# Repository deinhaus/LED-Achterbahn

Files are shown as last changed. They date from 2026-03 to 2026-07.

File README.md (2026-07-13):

GitHub Logo

Maker Media GmbH

***

# LED-Achterbahn

**Aus einem LED-Streifen, etwas Physik und einem ESP32 entsteht eine LED-Achterbahn, bei der das Licht wie ein echter Wagen durch Loopings und Kurven rauscht. Und das zugehörige Baukastensystem macht individuelle Streckendesigns zum Kinderspiel – ganz ohne Kleben, Schrauben oder manuelle Code-Anpassungen.**

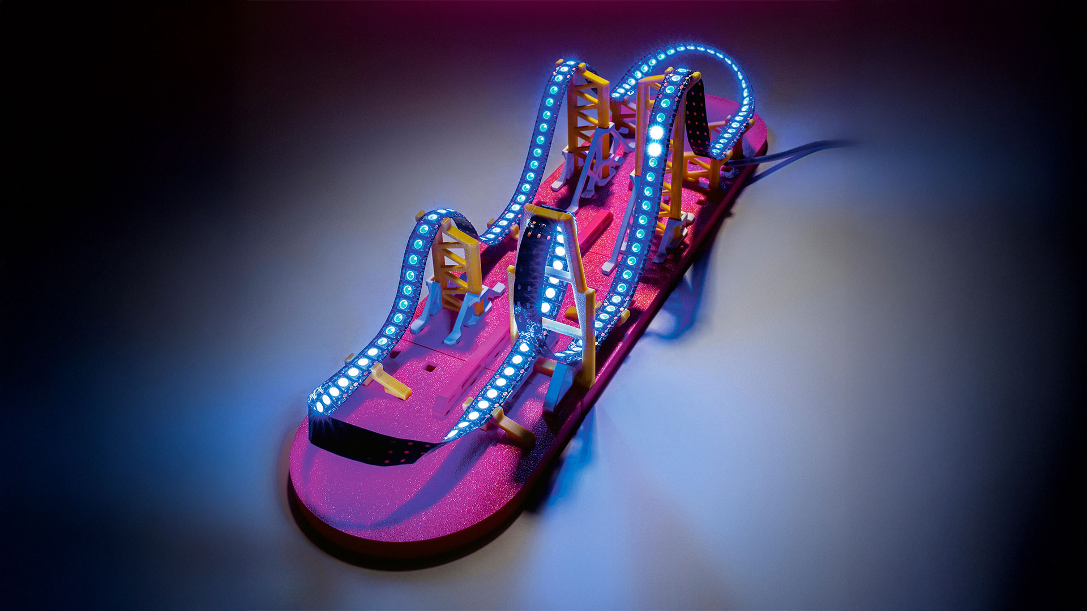
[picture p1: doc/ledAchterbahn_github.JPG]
Aufmacherbild aus dem Heft


Hier findet ihr die Daten für den 3D-Druck und den Arduino-Code.

Der vollständige Artikel zum Projekt steht in der **[Make-Ausgabe 2/26](https://www.heise.de/select/make/2026/2)**.

---
# Infos aus dem FORK<>

## umgesetzte Features
- ✅ Anbindung eines DFPlayer Mini für Audio-Effekte (Theme-Song, Zonen-Sounds, Zufallswiedergabe – siehe [Sound-System](#sound-system-dfplayer-mini))

## Hinweise zu G-Kräften in Telemetrie
Die G-Kräfte glätten (Der Code-Fix)
Da die Kurve in kleine lineare Stücke (Segmente) zerhackt wird, entstehen an den "Knickpunkten" zwischen den Segmenten oft winzige, aber extreme mathematische Spitzen in der Krümmung. Zudem ist ein echter Achterbahnzug lang und verteilt solche Spitzen.

Ich habe einen Tiefpassfilter (Moving Average) in den Code eingebaut, der die G-Kräfte weichzeichnet, wie es die Dämpfung eines echten Zuges tun würde. Zusätzlich habe ich die Auflösung der Kurven erhöht (const int intSteps = 40;) um eine feinere Abstufung zu erreichen.

Im Konfig-Menü ist jetzt ein Faktor konfigurierbar, der den angezeigten Wert n% abschwächt.

# Rollercoaster LED‑Simulation
*Interaktive Achterbahn‑Physik auf einem ESP32 mit OLED‑Display, Sound und bis zu 1000 LEDs.*








---

# 📖 Inhalt
1. [Überblick](#überblick)
2. [FPS‑Hinweise & Performance](#fps-hinweise--performance-tabelle)
3. [Features](#features)
4. [Hardware](#hardware)
5. [Verdrahtung](#verdrahtung)
6. [Stromversorgung](#stromversorgung)
7. [Installation](#installation)
8. [Sound-System (DFPlayer Mini)](#sound-system-dfplayer-mini)
9. [Bedienung & Menüsteuerung](#bedienung--menüsteuerung)
10. [Streckeneditor](#streckeneditor)
11. [Telemetrie & Kirmes-Modus](#telemetrie--kirmes-modus)
12. [Physik‑System](#physik-system)
13. [Dateisystem & Slots](#dateisystem--slots)
14. [Code‑Architektur](#code-architektur)
15. [Detaillierte Code‑Erklärung](#-detaillierte-code-erklärung)
16. [Troubleshooting Sound](#troubleshooting-sound)
17. [Lizenz](#lizenz)

---

# Überblick
- **rollercoaster_finale** ist **unverändert**.
- **Meine Änderungen** sind vollständig in **rollercoaster_extra** eingeflossen. Dieses Fork erweitert die Achterbahn um detailliertere Einstellungen, eine saubere Telemetrie mit Ziel-Logik, einen Kirmes-Modus mit dynamischen Sprüchen, eine optimierte Menüführung und ein vollständiges **Sound-System** auf Basis des DFPlayer Mini.

---

# FPS‑Hinweise & Performance‑Tabelle
Da der ESP32 gleichzeitig die Physik für bis zu 1000 LEDs berechnet und ein OLED-Display via I2C ansteuert, ist das richtige Timing entscheidend. Die folgende Tabelle zeigt, wie sich die Anzahl der LEDs auf die Datenraten, die maximal sinnvollen OLED‑FPS und das subjektive Fahrgefühl auswirken.

| **Anzahl LEDs** | **Zeit LED‑Daten** | **Zeit OLED‑Daten** | **Max. empfohlene OLED‑FPS** | **Effekt auf die LED‑Bahn** |
|---:|---:|---:|---:|---|
| 100  | 3 ms  | ~25 ms | 20–30 | Absolut flüssig, Ruckler nicht wahrnehmbar |
| 200  | 6 ms  | ~25 ms | 15–20 | Absolut flüssig |
| 300  | 9 ms  | ~25 ms | 15–20 | Sehr flüssig |
| 400  | 12 ms | ~25 ms | 12–15 | Sehr flüssig |
| 500  | 15 ms | ~25 ms | 10–15 | Flüssig |
| 600  | 18 ms | ~25 ms | 10–12 | Minimales Mikroruckeln messbar, kaum sichtbar |
| 700  | 21 ms | ~25 ms | 8–10  | Sehr stabiles Fahrgefühl |
| 800  | 24 ms | ~25 ms | 8–10  | Stabiles Fahrgefühl |
| 900  | 27 ms | ~25 ms | 6–8 | Leichte Ruckler beim Display‑Update möglich |
| 1000 | 30 ms | ~25 ms | 5–8 | Guter Kompromiss aus flüssiger Bahn und Telemetrie |

*Tipp: Die Display-FPS lassen sich im "Konfig"-Menü jederzeit anpassen. Standardwert ist 4 FPS.*

*Hinweis Sound: Die DFPlayer-Ansteuerung läuft über UART2 und wird bewusst ohne ACK-Wartezeiten betrieben (`isACK=false`), damit die Physik-Schleife nicht blockiert. Sound-Befehle haben dadurch keinen messbaren Einfluss auf die LED-Performance.*

---

# Features
- LED‑Achterbahn mit realistisch berechneter Physik
- Bis zu **1000 LEDs**
- **Sound-System mit 4 Modi:** Theme-Song mit Effekt-Einwürfen (Advertise), Zufallswiedergabe, nur Theme oder nur Effekte
- OLED‑Display mit Telemetrie (Aktiv/Ziel-Logik & Top-Speed Tracking)
- Vollständiger **Streckeneditor** direkt am Gerät mit Scroll-Menüs
- Lift, Brake, Booster, Loop, Helix, Steilkurve uvm.
- Zonen lassen sich temporär deaktivieren (Enabled/Disabled)
- Kirmes-Modus mit passenden Sprüchen zum jeweiligen Fahrabschnitt
- 5 Speicher‑Slots (LittleFS) inkl. Abwärtskompatibilität
- Farbcodierung nach Geschwindigkeit (Speed-Map)
- Bezier‑Interpolation für realistische Höhenprofile

---

# Hardware
- ESP32 DevKit (Empfohlen: ESP32-S3 für bessere FPU-Performance)
- SH1106 OLED 128×64 (I2C)
- WS2812B LED‑Strip
- Rotary Encoder mit Button (KY-040)
- **DFPlayer Mini** (⚠️ **Original YX5200 dringend empfohlen** – siehe [Troubleshooting](#troubleshooting-sound))
- microSD-Karte, max. 32 GB, FAT32
- Mono-Lautsprecher 4–8 Ω, max. 3 W
- 1 kΩ Widerstand (für die RX-Leitung des DFPlayer)
- Elko 470–1000 µF (Pufferung der DFPlayer-Versorgung)
- 5V Netzteil (je nach LED‑Anzahl 5–20A)

---

# Verdrahtung

## Pinbelegung ESP32

| ESP32-Pin | verbunden mit |
|---|---|
| GPIO 33 | LED-Streifen Datenleitung (DIN) |
| GPIO 25 | Encoder CLK |
| GPIO 26 | Encoder DT |
| GPIO 27 | Encoder Taster (SW) |
| GPIO 21 | OLED SDA (I2C) |
| GPIO 22 | OLED SCL (I2C) |
| GPIO 17 | DFPlayer RX (**über 1 kΩ Widerstand!**) |
| GPIO 16 | DFPlayer TX (direkt) |

## Anschluss DFPlayer Mini

Modul so halten, dass der SD-Karten-Slot nach oben zeigt. Pin 1 (VCC) ist dann oben links; die linke Seite zählt von oben nach unten durch.

| DFPlayer-Pin  | verbunden mit |
|---|---|
| VCC (Pin 1) | 5 V |
| RX  (Pin 2) | ESP32 GPIO 17, **1 kΩ Widerstand in Serie** |
| TX  (Pin 3) | ESP32 GPIO 16 (direkt) |
| SPK_1 (Pin 6) | Lautsprecher + |
| GND (Pin 7) | Masse (gemeinsam mit ESP32 und Netzteil!) |
| SPK_2 (Pin 8) | Lautsprecher − |

Alle übrigen Pins (BUSY, DAC, ADKEY, IO, USB) bleiben frei. Die freien Pins der rechten Modulseite dürfen nichts berühren – ADKEY/IO lösen sonst ungewollt Wiedergabe aus.

Der 1-kΩ-Widerstand dämpft den Pegelunterschied zwischen dem 3,3-V-Signal des ESP32 und dem 5-V-Eingang des Players. Ohne ihn funktioniert die Kommunikation zwar, es entsteht aber häufig ein leises Dauerrauschen im Lautsprecher.

---

# Stromversorgung

⚠️ **Der häufigste Fehler beim Nachbau:** LED-Streifen und Sound gemeinsam am USB-Port betreiben. Die Folge sind Brummen aus dem Lautsprecher, abgehackte Sounds, Ruckler und komplette Systemabstürze, die nur ein Kaltstart behebt.

Regeln für einen stabilen Betrieb:
- **LED-Streifen zwingend an ein ausreichend dimensioniertes 5-V-Netzteil**, niemals inkl. Sound über USB versorgen.
- Bei 1000 LEDs den Strom an **mehreren Punkten** einspeisen (Anfang, Mitte, Ende).
- **Elko 470–1000 µF direkt an VCC/GND des DFPlayer** (Polung beachten: Minus-Streifen an GND). Puffert die Stromspitzen des 3-W-Verstärkers.
- **Alle Massen verbinden** (Netzteil, ESP32, DFPlayer, LED-Streifen), sternförmig zum Netzteil geführt – nicht als lange Kette.
- Der ESP32 selbst kann am USB bleiben (praktisch zum Flashen), der DFPlayer sollte mit eigener Zuleitung ans Netzteil.
- Nach Tests das System **10–15 Sekunden stromlos** lassen: Der Elko hält den DFPlayer sonst am Leben und alte Zustände (Loop-Modus, Lautstärke) überleben den vermeintlichen Neustart.

---

# Installation
1. Repository klonen
2. Arduino IDE öffnen (ESP32 Boardverwalter muss installiert sein)
3. Bibliotheken installieren:
   - Adafruit GFX Library
   - Adafruit SH110X
   - Adafruit NeoPixel
   - RotaryEncoder (von Matthias Hertel)
   - LittleFS (ESP32)
   - **DFRobotDFPlayerMini** (von DFRobot)
4. Taktfrequenz in der IDE auf 240 MHz stellen (für maximale Physik-Performance).
5. SD-Karte für den DFPlayer vorbereiten (siehe [Sound-System](#sound-system-dfplayer-mini)).
6. Sketch hochladen.

---

# Sound-System (DFPlayer Mini)

## SD-Karten-Struktur

- Max. 32 GB, **FAT32** formatiert (nicht exFAT – Karten über 32 GB formatiert Windows standardmäßig als exFAT!)
- Dateien **einzeln in numerischer Reihenfolge** kopieren (der Player adressiert intern nach FAT-Reihenfolge)
- Bei macOS versteckte `._`-Dateien entfernen: `dot_clean /Volumes/SD`

```
SD-Karte (Root)
├── mp3/
│   ├── 0001.mp3   Kettenlift          (Modus "Effekte")
│   ├── 0002.mp3   Booster / Launch    (Modus "Effekte")
│   ├── 0003.mp3   Bremse / Zischen    (Modus "Effekte")
│   ├── 0004.mp3   Theme-Song          (Modus "Theme+FX" und "Theme")
│   └── 0005.mp3   Welcome / Start     (Modus "Effekte", beim Fahrtbeginn)
├── ADVERT/
│   ├── 0001.mp3   Kettenlift   ┐
│   ├── 0002.mp3   Booster      ├─ identische Dateien wie /mp3/0001–0003,
│   └── 0003.mp3   Bremse       ┘  als Einwurf für Modus "Theme+FX"
└── 02/
    ├── 001.mp3    ┐
    ├── 002.mp3    ├─ beliebig viele Random-Tracks (Modus "Random"),
    └── ...        ┘  lückenlos nummeriert
```

**Namenskonventionen:**
- `/mp3` und `/ADVERT`: Dateinamen mit **vier** Ziffern (`0001.mp3`)
- Nummerierte Ordner (`02`): Ordnername **zwei** Ziffern, Dateien **drei** Ziffern (`001.mp3`)
- Der Ordnername `ADVERT` muss exakt so lauten (Großbuchstaben)

## Die vier Sound-Modi

| Modus | Verhalten |
|---|---|
| **Theme+FX** | Theme-Song läuft in Schleife. Fährt der Wagen in eine Zone, wird der passende Effekt per **Advertise** eingeblendet – danach läuft der Theme automatisch an der unterbrochenen Stelle weiter. Verlässt der Wagen den Lift, wird dessen Sound sofort beendet (`stopAdvertise`). |
| **Random** | Zufällige Tracks aus `/02` in Endlosschleife. Läuft komplett ununterbrochen – Zonen haben keinen Einfluss. |
| **Theme** | Nur der Theme-Song in Schleife, keine Effekte. |
| **Effekte**  | Stille bei freier Fahrt; Zonen-Sounds als Einzeltracks (Lift loopt, Booster/Bremse laufen einmal aus). Beim Fahrtstart wird der Welcome-Sound gespielt, geschützt durch eine Schonfrist. |

## Technische Details
- Kommunikation über **UART2** (Hardware-Serial, 9600 Baud)
- Initialisierung mit `begin(dfpSerial, /*isACK=*/false, /*doReset=*/true)`: Der abgeschaltete ACK-Check verhindert, dass Befehle wie `stop()` die Hauptschleife blockieren; der Reset sorgt für einen definierten Startzustand. Bis zu 3 Initialisierungsversuche.
- Die Anzahl der Random-Tracks wird beim Boot per `readFileCountsInFolder()` ermittelt (doppelte Abfrage, da der erste Wert nach dem Reset unzuverlässig sein kann).
- Die Sound-Logik reagiert auf **Kategorie-Wechsel** (LIFT/BOOST/BRAKE/RIDE), nicht auf jeden Statuswechsel – "FREIE FAHRT" und "AUSROLLEN" teilen sich einen Sound, damit Tracks nicht grundlos abbrechen.
- Track-Wiederholung (Theme, Lift-Loop) läuft über den `DFPlayerPlayFinished`-Event statt über den unzuverlässigen internen Loop-Modus. Eine 300-ms-Sperre fängt doppelte Finish-Events ab.

---

# Bedienung & Menüsteuerung
Die komplette Steuerung erfolgt intuitiv über den **Drehencoder**:
- **Drehen:** Navigiert durch Listen oder ändert Werte.
- **Drücken:** Bestätigt eine Auswahl oder wechselt in die nächste Menüebene.

### Das Hauptmenü
- **ABSPIELEN:** Startet die Echtzeit-Simulation der aktuell geladenen Strecke.
- **KONFIG:** Hier lassen sich visuelle und akustische Parameter anpassen:
  - Wagen- und Bahnfarbe (inkl. Speed-Map)
  - Helligkeit für Wagen, Bahn und Zonen (Lift, Brake, Booster)
  - Wagenlänge (Anzahl der LEDs)
  - Zonen-Effekte (Aus, Statisch, Lauflicht/Pulsieren)
  - OLED FPS und Display-Modus (Telemetrie vs. Kirmes)
  - Hilfparameter (G-Factor, MaxSpeed für color-speed-map)
  - **Sound-V:** Lautstärke 0–30, mit Live-Hörprobe beim Drehen
  - **Sound:** Sound global An/Aus
  - **S-Modus:** Auswahl des Sound-Modus (Theme+FX / Random / Theme / Effekte)
- **STRECKE ANPASSEN:** Zugang zum Streckeneditor (Bearbeiten, Neu hinzufügen).
- **STRECKEN [Sx]:** Dateimanager. Zeigt den aktuell geladenen Slot (S1-S5) an.

*Hinweis: Längere Menüs (wie z.B. bei der Element-Bearbeitung oder Konfig) verfügen über einen **dynamischen Scroll-Viewport**, sodass immer 6-7 Zeilen sichtbar sind und der Cursor flüssig mitläuft.*

*Wichtig: Einstellungen werden erst beim Verlassen des KONFIG-Menüs über ZURUECK in den aktiven Slot gespeichert.*

---

# Streckeneditor
Der Editor ermöglicht es, die physikalischen Eigenschaften der Strecke direkt am LED-Band zu "zeichnen". Die Strecke besteht aus "Nodes" (Knotenpunkten).

1. **Startpunkt setzen:** Definiert die Position (LED) und die Starthöhe.
2. **Elemente hinzufügen:** Du navigierst die "grüne LED" an die gewünschte Position auf dem Streifen, stellst die Höhe ein und wählst die Art des Elements (Hill, Loop, Helix, etc.).
3. **Funktions-Zonen (Lift, Brake, Booster):** Diese speziellen Elemente benötigen weitere Parameter:
   - **Wert (Force):** m/s für Lift/Bremse oder Schubkraft für den Booster.
   - **Länge:** Wie viele LEDs lang diese Zone aktiv sein soll.
   - **Aktiv/Inaktiv:** Zonen können zu Testzwecken schnell an- oder ausgeschaltet werden, ohne sie löschen zu müssen.
4. **Endpunkt:** Schließt die Strecke ab. Das System berechnet automatisch die Bezier-Kurven und die Beschleunigungswerte für jedes Teilstück dazwischen.

---

# Telemetrie & Kirmes-Modus
Während der Fahrt liefert das OLED-Display Live-Daten. Es gibt zwei Darstellungsmodi, die im Konfig-Menü umgestellt werden können.

### Modus 0: Telemetrie (Der Nerd-Modus)
Liefert exakte Daten zur Physik-Engine:
- **Pos:** Aktuelle LED-Position des Wagens / Gesamtlänge.
- **Spd m/s:** Aktuelle Geschwindigkeit in Metern pro Sekunde, inkl. der **(max xx.x)** Anzeige für den bisherigen Top-Speed des Runs.
- **G:** Aktuelle G-Kräfte inkl. der **(max xx.x/min xx.x)** Anzeige für den bisherigen Top-Wert des Runs.
- **Status:** Zeigt an, ob der Wagen frei fährt (FREIE FAHRT), gebremst wird, auf dem Lift hängt oder geboostet wird.
- **Ziele & Zonen:**
  - `AKTIV: Elem X (Typ)`: Wird angezeigt, solange sich der Wagen *physisch innerhalb* der Länge einer Zone (z.B. eines Lifts) befindet.
  - `ZIEL: Elem Y (Typ)`: Fährt der Wagen frei, zeigt das System das nächste vorausliegende Element an.
- **LED & H:** Genaue Position und Höhe des aktuellen/nächsten Elements.

### Modus 1: Jahrmarkt Live (Der Show-Modus)
Perfekt, wenn die Bahn fertig aufgebaut ist. Zeigt nur den aktuellen Speed (inkl. Max) und präsentiert einen zufällig gewählten, dynamischen Spruch passend zur aktuellen Streckensituation (z.B. *"Zischhh... Bremsen greifen!"* oder *"Kopfueber ins Glueck! Looping in Sicht!"*). In Kombination mit dem Sound-Modus **Theme+FX** entsteht so echtes Kirmes-Feeling.

---

# Physik‑System
Das Kernstück der Simulation. Der Code unterteilt die Bezier-Interpolation der Strecke in winzige Segmente.
- **Beschleunigung:** Wird durch den Hangabtrieb ($a = g \cdot \sin(\alpha)$) in jedem Segment bestimmt.
- **Reibung & Luftwiderstand:** Wirken dynamisch gegen die Bewegungsrichtung, abhängig von der aktuellen Geschwindigkeit ($v^2$).
- **Funktionszonen:** Überschreiben die Physik. Ein Lift zwingt den Wagen auf eine konstante Geschwindigkeit, eine Bremse baut Energie ab, ein Booster addiert Beschleunigung.
- Die Berechnung erfolgt zeitbasiert (`dt = millis() - lastTime`), um die Geschwindigkeit unabhängig von der CPU-Auslastung stabil zu halten.

---

# Dateisystem & Slots
Die Strecken werden im Flash-Speicher des ESP32 via LittleFS abgelegt.
- Bis zu **5 Strecken** speicherbar (Slot 1 bis Slot 5).
- Speichert alle Nodes, Optik-Einstellungen, Helligkeiten, FPS **und die Sound-Einstellungen** (Lautstärke, An/Aus, Sound-Modus).
- **Migration / Abwärtskompatibilität:** Der Code nutzt einen `FILE_MAGIC` Header mit Versionsnummer (aktuell **V6**). Alte Strecken werden beim Laden automatisch migriert: fehlende Felder erhalten sinnvolle Standardwerte (z.B. Zonen auf aktiv, Lautstärke 20, Sound-Modus Theme+FX).
- Funktionen: Laden, Neu erstellen (löscht den RAM und beginnt bei LED 0), Neu berechnen (falls die Bezier-Kurven haken) und Löschen (entfernt die .bin Datei aus dem Flash).

---

# Code‑Architektur
- **State‑Machine (UI_STATE):** Über 40 Zustände steuern, was gerade auf dem Display gerendert wird und wie der Encoder reagiert (z.B. `ST_EDIT_NODE_FORCE`, `ST_OPTICS_SOUND_MODE` oder `ST_PLAY`).
- **Nodes (`Node`):** Die Stützpfeiler der Strecke. Enthalten Typ, Höhe und ggf. Spezialfunktionen.
- **Bezier‑Interpolation (`calculations`, `bezierCalculations`):** Generiert aus wenigen Nodes eine geschwungene, realistische Bahn.
- **Segment‑Physik (`segmentCalculations`):** Wandelt die Bezier-Punkte in physikalische Steigungen um.
- **Sound-Logik (`updateSound`, `playRandomSound`, `stopSound`):** Bildet den Fahrstatus auf Sound-Kategorien ab und steuert den DFPlayer je nach gewähltem Modus. Der `DFPlayerPlayFinished`-Event in `moveLED()` übernimmt Theme-Wiederholung, Lift-Loop und Random-Weiterschaltung.
- **Renderer:** Getrennte Ausgabe für LEDs (`moveLED`, `drawSetupLeds`, `drawColorSelection`) und das Display (vielfältige `draw...` Funktionen).

---

# 🧩 Detaillierte Code‑Erklärung

## Bibliotheken & Hardware‑Setup
Der Code nutzt:
- `Adafruit_SH1106G` → OLED‑Display (I2C)
- `Adafruit_NeoPixel` → LED‑Streifen (WS2812B)
- `RotaryEncoder` → Interrupt-basierte Encoder-Auswertung für präzises Drehen.
- `LittleFS` → Dateisystem
- `Wire` → I²C für Display
- `DFRobotDFPlayerMini` → Sound-Ausgabe über UART2 (GPIO 16/17)

## Datenstrukturen

### Node
```cpp
struct Node {
  uint16_t pos;      // Position auf dem LED-Streifen
  uint16_t height;   // "Bauhöhe" des Elements
  uint8_t  type;     // 0=Start, 1=Scheitel, 2=Ende
  uint8_t  art;      // Welches Streckenelement (Hill, Loop, Lift...)
  float    force;    // Kraft/Zielgeschwindigkeit
  uint16_t length;   // Ausdehnung des Elements in LEDs
  uint8_t  enabled;  // 1 = Aktiviert, 0 = Übersprungen
};
```

### Sound-Konstanten
```cpp
#define SND_LIFT      1    // /mp3/0001.mp3 (Modus "Effekte")
#define SND_BOOSTER   2    // /mp3/0002.mp3
#define SND_BRAKE     3    // /mp3/0003.mp3
#define SND_THEME     4    // /mp3/0004.mp3 (Modi "Theme+FX" und "Theme")
#define SND_START     5    // /mp3/0005.mp3 (Welcome im Modus "Effekte")
#define ADV_LIFT      1    // /ADVERT/0001.mp3 (Einwürfe im Modus "Theme+FX")
#define ADV_BOOSTER   2    // /ADVERT/0002.mp3
#define ADV_BRAKE     3    // /ADVERT/0003.mp3
#define RANDOM_FOLDER 2    // Ordner /02 (Modus "Random")
```

---

# Troubleshooting Sound

| Symptom | Ursache | Lösung |
|---|---|---|
| "DFPlayer nicht gefunden" | RX/TX vertauscht, fehlende gemeinsame Masse oder SD-Indizierung noch nicht fertig | Leitungen kreuzen (TX→RX), alle GND verbinden, `delay(1000)` vor `begin()` |
| Ordner wird als leer gemeldet, Abspielen geht aber | Clone-Chip (z.B. GD3200B, MH2024K) – `readFileCountsInFolder()` defekt | Original YX5200 verwenden oder Track-Anzahl fest im Code hinterlegen |
| Spontanes Abspielen beim Einschalten | Clone-Chip mit Auto-Play oder freischwebende ADKEY/IO-Pins | Original verwenden; rechte Pin-Reihe freihalten |
| Brummen, das lauter wird und mit Knacken endet | Verstärker schwingt in der Boot-Phase auf verrauschter Versorgung | LED-Streifen an eigenes Netzteil, Elko an den Player, 1-kΩ-Widerstand |
| Brummen/Kratzen im Betrieb, System friert ein | LED-Streifen und Player teilen sich die USB-Versorgung | **Separates Netzteil für die LEDs** – wichtigste Einzelmaßnahme!  Ich versorge alles mit einem 5V/5A Netzteil, über USB kann der Strom ggf nicht genügen, wenn zu viele LEDs gleichzeitig oder zu hell leuchten. |
| `stop()` oder andere Befehle hängen | Bibliothek wartet auf ACK-Antwort, Rückleitung (Player-TX) gestört | `begin(..., /*isACK=*/false, ...)` verwenden, TX-Leitung prüfen |
| Sounds brechen ab, neuer Track startet mitten drin | Sound-Logik reagiert auf jeden Statuswechsel | Im aktuellen Code behoben (Kategorie-Abbildung) |
| Alte Einstellungen überleben den Neustart | Elko hält den Player nach dem Ausstecken am Leben | 10–15 Sekunden stromlos lassen |

---

# Lizenz
Siehe Original-Repository / Make-Ausgabe 2/26.

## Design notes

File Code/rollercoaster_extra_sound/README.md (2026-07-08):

# LED-Achterbahn mit Sound (ESP32 + DFPlayer Mini)

LED-Achterbahn-Simulation auf einem WS2812-Streifen (bis 1000 LEDs) mit physikbasierter
Wagenbewegung, OLED-Menü, Drehencoder-Bedienung und Soundausgabe über einen DFPlayer Mini.

---

## Hardware

| Komponente | Typ / Hinweis |
|---|---|
| Mikrocontroller | ESP32 |
| LED-Streifen | WS2812 (NeoPixel), bis 1000 LEDs |
| Display | OLED SH1106, 128x64, I2C (Adresse 0x3C) |
| Bedienung | Drehencoder mit Taster |
| Sound | DFPlayer Mini (**Original YX5200 empfohlen!**) |
| Lautsprecher | Mono, 4-8 Ohm, max. 3 W |
| Netzteil | 5 V / 10 A (fuer LED-Streifen zwingend!) |

> **Wichtig:** Clone-DFPlayer (z. B. GD3200B, MH2024K) verursachen Probleme:
> falsche Ordner-Zaehlung, defektes loop(), spontanes Abspielen beim Einschalten.
> Ein Original-Modul erspart viel Fehlersuche.

---

## Pinbelegung ESP32

| ESP32-Pin | verbunden mit |
|---|---|
| GPIO 33 | LED-Streifen Datenleitung (DIN) |
| GPIO 25 | Encoder CLK |
| GPIO 26 | Encoder DT |
| GPIO 27 | Encoder Taster (SW) |
| GPIO 21 | OLED SDA (I2C) |
| GPIO 22 | OLED SCL (I2C) |
| GPIO 17 | DFPlayer RX (**ueber 1 kOhm Widerstand!**) |
| GPIO 16 | DFPlayer TX |

## Anschluss DFPlayer Mini

Modul so halten, dass der SD-Karten-Slot nach oben zeigt.
Pin 1 (VCC) ist dann oben links; die linke Seite zaehlt von oben nach unten.

| DFPlayer-Pin | verbunden mit |
|---|---|
| VCC (Pin 1)  | 5 V |
| RX  (Pin 2)  | ESP32 GPIO 17, **1 kOhm Widerstand in Serie** |
| TX  (Pin 3)  | ESP32 GPIO 16 (direkt) |
| SPK_1 (Pin 6)| Lautsprecher + |
| GND (Pin 7)  | Masse (gemeinsam mit ESP32 und Netzteil!) |
| SPK_2 (Pin 8)| Lautsprecher - |

Alle uebrigen Pins (BUSY, DAC, ADKEY, IO, USB) bleiben frei.
Freie Pins der rechten Seite nicht beruehren lassen - ADKEY/IO loesen sonst
ungewollt Wiedergabe aus.

### Stromversorgung (wichtig!)

- **LED-Streifen zwingend an ein eigenes 5-V-Netzteil** - niemals ueber den
  USB-Port versorgen. Ein gemeinsamer USB-Betrieb fuehrt zu Brummen aus dem
  Lautsprecher, Sound-Aussetzern und Systemabstuerzen.
- Bei 1000 LEDs: Strom an **mehreren Punkten** einspeisen (Anfang, Mitte, Ende),
  Kabelquerschnitt mind. 1,5 mm².
- **Elko 470-1000 uF** direkt an VCC/GND des DFPlayer (Polung beachten).
- **Alle Massen verbinden** (Netzteil, ESP32, DFPlayer, LED-Streifen),
  sternfoermig zum Netzteil gefuehrt.
- Der ESP32 selbst kann am USB bleiben (praktisch zum Flashen).

### Software-Hinweis zur Initialisierung

Der DFPlayer wird mit `dfPlayer.begin(dfpSerial, /*isACK=*/false, /*doReset=*/true)`
initialisiert: Der abgeschaltete ACK-Check verhindert, dass Befehle wie `stop()`
blockieren; der Reset sorgt fuer einen definierten Startzustand.
Nach Tests das System **10-15 Sekunden stromlos** lassen - der Elko haelt den
Player sonst am Leben und alte Zustaende (Loop-Modus etc.) bleiben erhalten.

---

## SD-Karte (DFPlayer)

- Max. 32 GB, **FAT32** formatiert (nicht exFAT!)
- Dateien in numerischer Reihenfolge einzeln kopieren (FAT-Reihenfolge!)
- Bei macOS: versteckte `._`-Dateien entfernen (`dot_clean /Volumes/SD`)

```
SD-Karte (Root)
├── mp3/
│   ├── 0001.mp3   Kettenlift          (Modus "Effekte")
│   ├── 0002.mp3   Booster / Launch    (Modus "Effekte")
│   ├── 0003.mp3   Bremse / Zischen    (Modus "Effekte")
│   ├── 0004.mp3   Theme-Song          (Modus "Theme+FX" und "Theme")
│   └── 0005.mp3   Welcome / Start     (Modus "Effekte", beim Fahrtbeginn)
├── ADVERT/
│   ├── 0001.mp3   Kettenlift   ┐
│   ├── 0002.mp3   Booster      ├─ identische Dateien wie /mp3/0001-0003,
│   └── 0003.mp3   Bremse       ┘  als Einwurf fuer Modus "Theme+FX"
└── 02/
    ├── 001.mp3    ┐
    ├── 002.mp3    ├─ beliebig viele Random-Tracks (Modus "Random"),
    └── ...        ┘  lueckenlos nummeriert, drei Ziffern
```

**Namenskonventionen beachten:**
- `/mp3` und `/ADVERT`: Dateinamen mit **vier** Ziffern (`0001.mp3`)
- Nummerierte Ordner (`02`): Ordnername **zwei** Ziffern, Dateien **drei** Ziffern (`001.mp3`)

---

## Sound-Modi (KONFIG-Menue > S-Modus)

| Modus | Verhalten |
|---|---|
| Theme+FX | Theme-Song laeuft in Schleife; Zonen-Effekte (Lift, Booster, Bremse) werden per Advertise eingeblendet, danach laeuft der Theme an alter Stelle weiter |
| Random | Zufaellige Tracks aus `/02` in Endlosschleife, keine Unterbrechungen |
| Theme | Nur der Theme-Song in Schleife, keine Effekte |
| Effekte | Stille bei freier Fahrt; Zonen-Sounds als Einzeltracks, Welcome beim Start |

Weitere Sound-Einstellungen im KONFIG-Menue: Lautstaerke (0-30, mit Hoerprobe)
und Sound An/Aus. Alle Einstellungen werden im aktiven Strecken-Slot gespeichert
(beim Verlassen des Menues ueber ZURUECK).

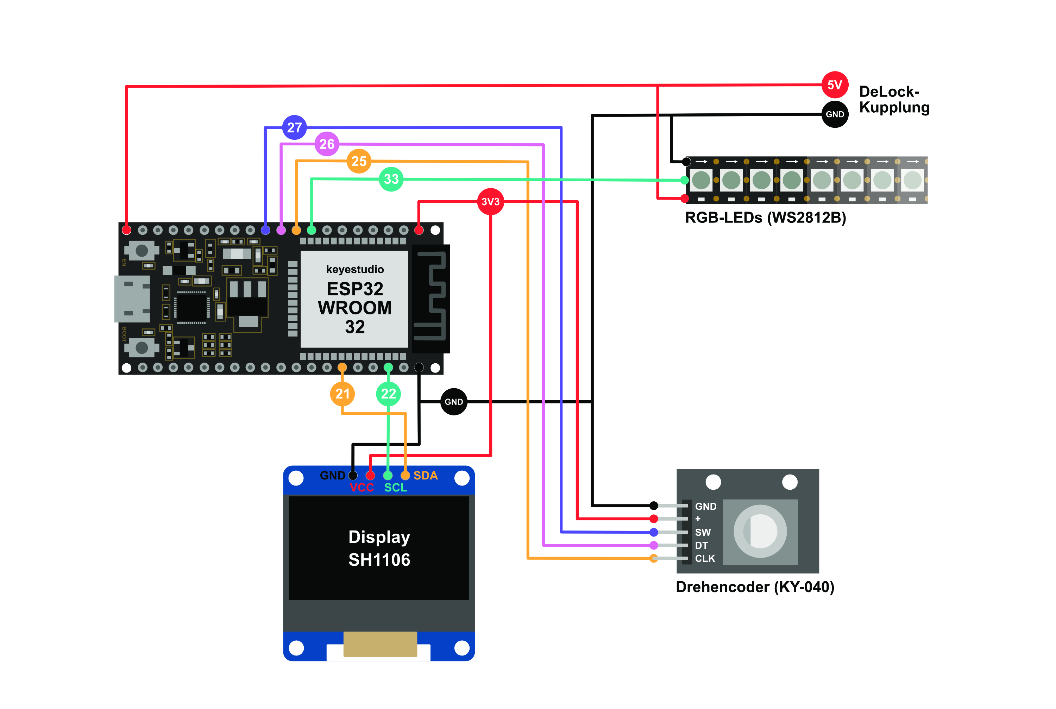
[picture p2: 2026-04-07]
ledAchterbahn_schaltplan.jpg

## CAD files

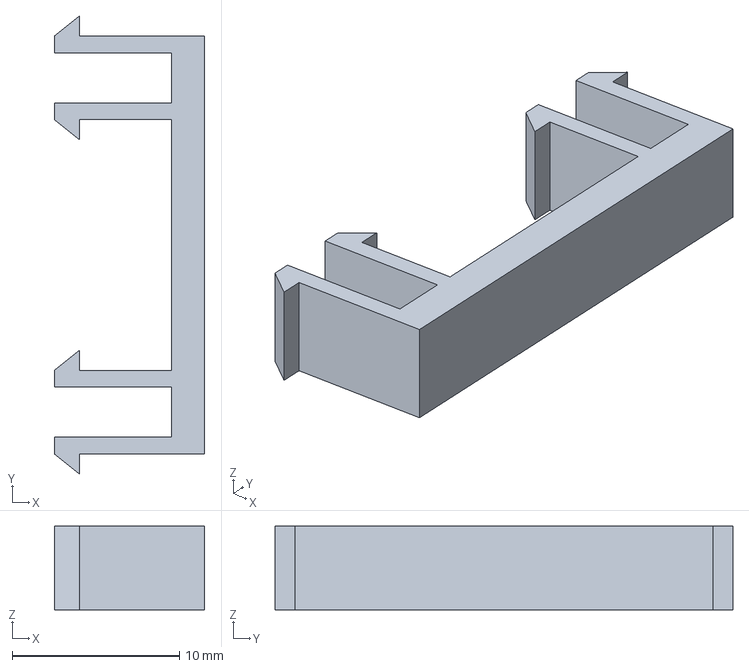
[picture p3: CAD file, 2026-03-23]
3D-Druck/STEP/base.stp
9.00 x 27.4 x 5.00 mm

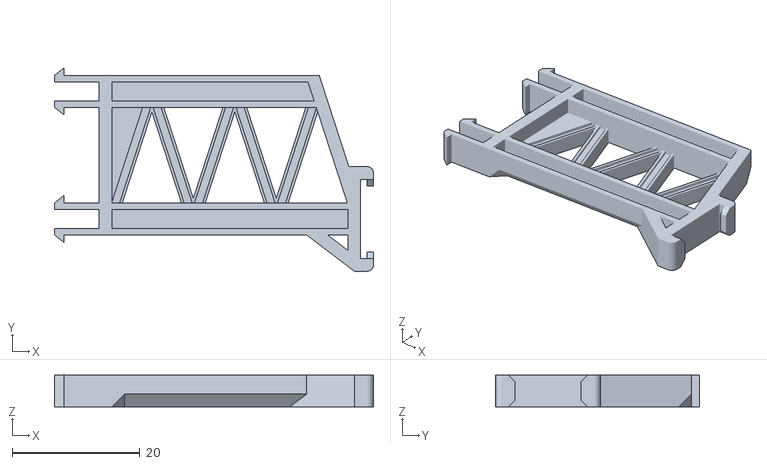
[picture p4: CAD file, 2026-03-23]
3D-Druck/STLs/stuetze_5.stl
50.0 x 31.9 x 5.00

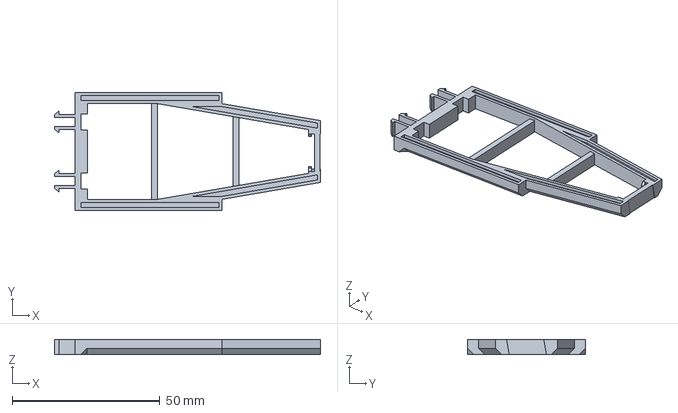
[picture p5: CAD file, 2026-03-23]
3D-Druck/STEP/stuetze_looping_11.stp
90.0 x 39.8 x 5.00 mm

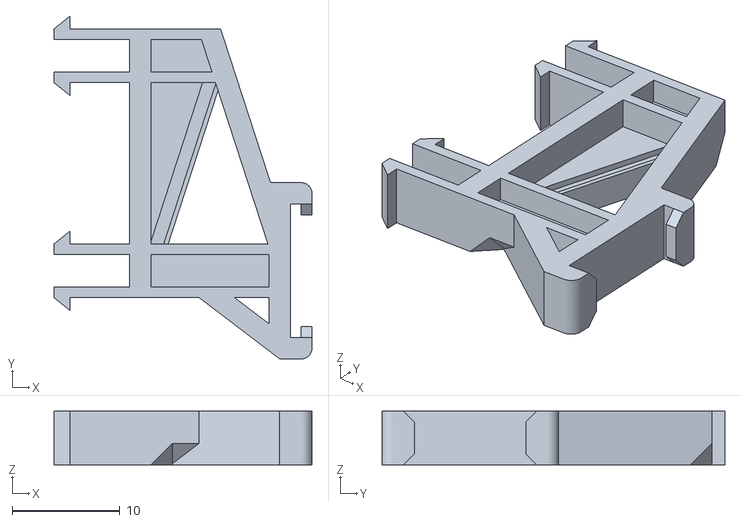
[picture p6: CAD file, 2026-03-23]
3D-Druck/STLs/stuetze_1.stl
24.0 x 31.9 x 5.00

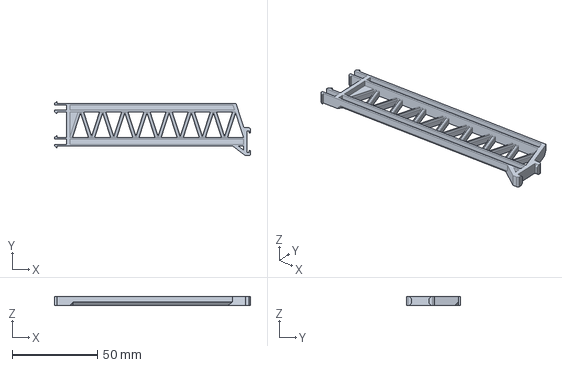
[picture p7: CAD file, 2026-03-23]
3D-Druck/STEP/stuetze_15.stp
115.0 x 31.9 x 5.00 mm

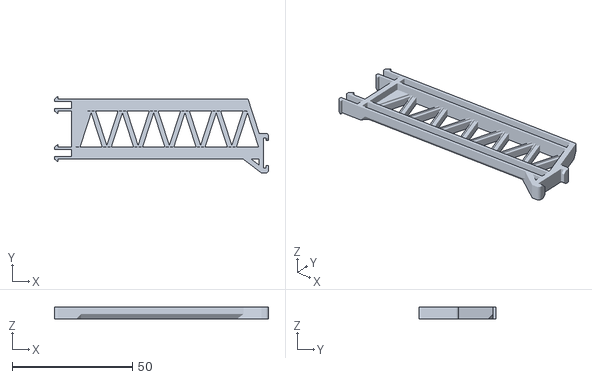
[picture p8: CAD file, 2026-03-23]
3D-Druck/STLs/stuetze_11.stl
89.0 x 31.9 x 5.00

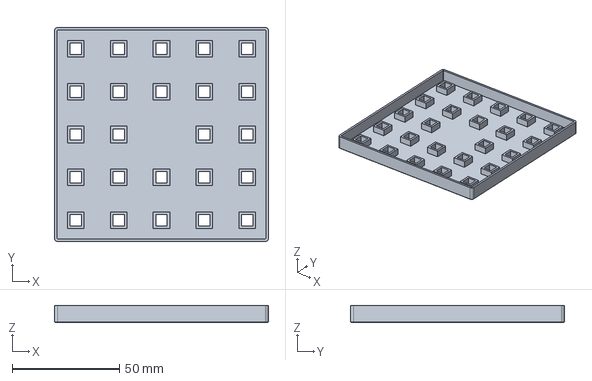
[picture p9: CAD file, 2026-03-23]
3D-Druck/STEP/boden_quadratisch.stp
99.8 x 99.8 x 8.00 mm

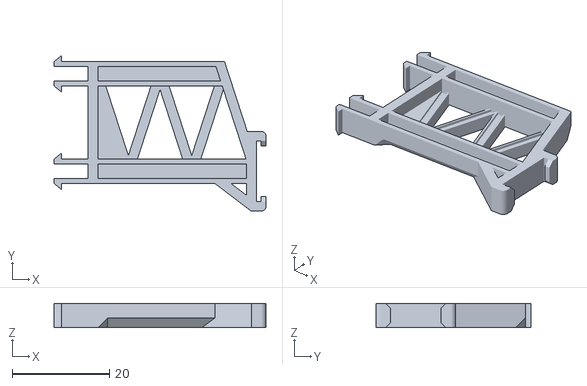
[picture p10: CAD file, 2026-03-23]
3D-Druck/STLs/stuetze_4.stl
43.5 x 31.9 x 5.00

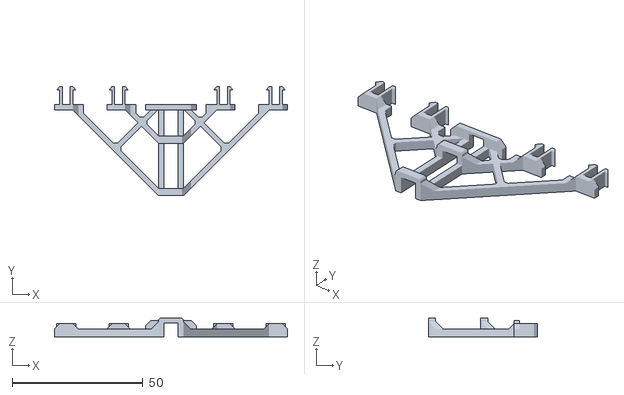
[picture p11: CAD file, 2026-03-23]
3D-Druck/STLs/stuetze_seite_g.stl
89.0 x 41.8 x 7.13

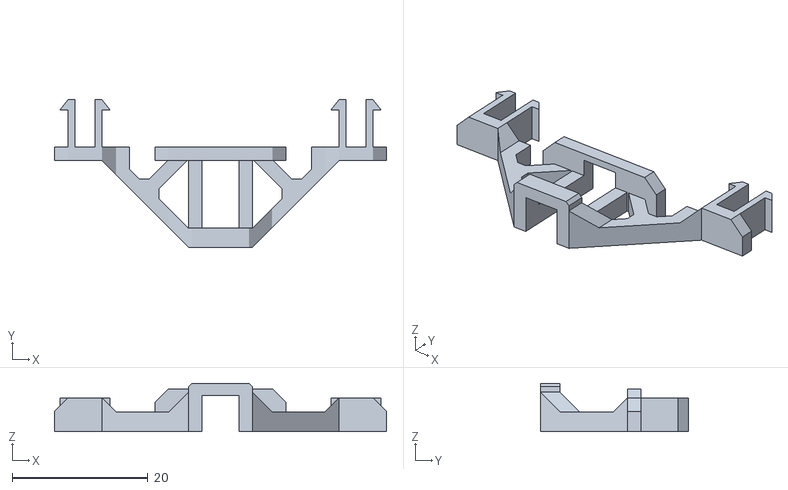
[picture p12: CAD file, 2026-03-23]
3D-Druck/STLs/stuetze_seite_k.stl
49.0 x 21.8 x 7.13

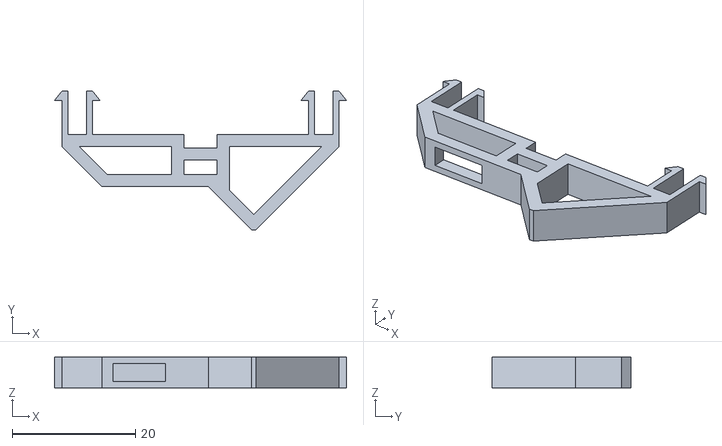
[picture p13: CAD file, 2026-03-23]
3D-Druck/STLs/stuetze_looping_boden.stl
47.4 x 22.5 x 5.00

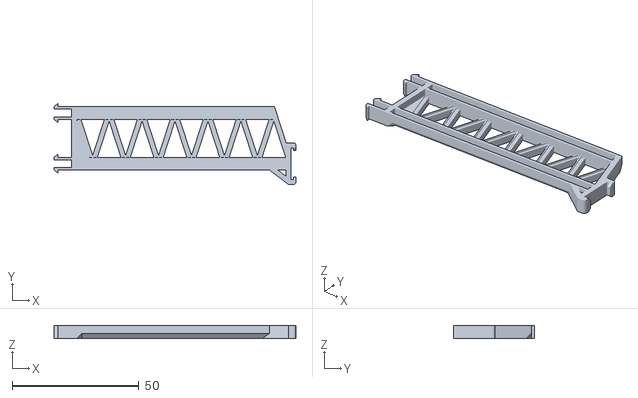
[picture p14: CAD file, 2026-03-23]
3D-Druck/STLs/stuetze_12.stl
95.5 x 31.9 x 5.00

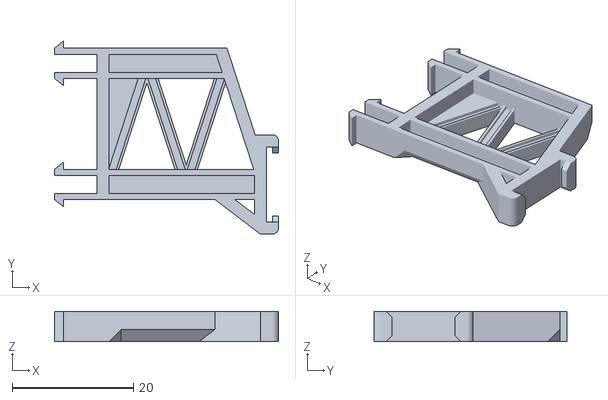
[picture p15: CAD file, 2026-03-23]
3D-Druck/STLs/stuetze_3.stl
37.0 x 31.9 x 5.00

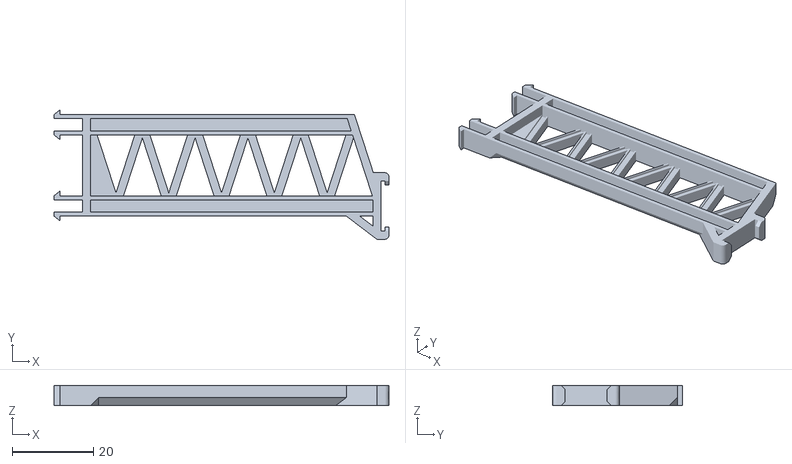
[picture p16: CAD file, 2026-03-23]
3D-Druck/STLs/stuetze_10.stl
82.5 x 31.9 x 5.00

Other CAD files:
3D-Druck/STLs/controller_deckel.stl
3D-Druck/STLs/stuetze_8.stl
3D-Druck/STLs/stuetze_0.stl
3D-Druck/STLs/stuetze_6.stl
3D-Druck/STLs/boden_quadratisch.stl
3D-Druck/STLs/boden_rund.stl
3D-Druck/STLs/boden_verbinder.stl
3D-Druck/STLs/controller_boden.stl
3D-Druck/STLs/controller_drehknopf.stl
3D-Druck/STLs/controller_front.stl
3D-Druck/STLs/stuetze_13.stl
3D-Druck/STLs/stuetze_14.stl
3D-Druck/STLs/stuetze_15.stl
3D-Druck/STLs/stuetze_2.stl
3D-Druck/STLs/stuetze_7.stl
3D-Druck/STLs/stuetze_9.stl
3D-Druck/STLs/stuetze_looping_11.stl

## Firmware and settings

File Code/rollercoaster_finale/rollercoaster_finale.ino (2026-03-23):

#include <Arduino.h>
#include <Wire.h>
#include <Adafruit_GFX.h>
#include <Adafruit_SH110X.h>
#include <RotaryEncoder.h>
#include <Adafruit_NeoPixel.h>
#include <LittleFS.h>

// Datei für Daten in LittleFS
#define LEDCFG_FILE "/ledcfg.bin"

// LED-STREIFEN
#define LED_PIN 33

// DREHENCODER-EINSTELLUNGEN
#define PIN_CLK 25
#define PIN_DT 26
#define PIN_SW 27
RotaryEncoder encoder(PIN_CLK, PIN_DT, RotaryEncoder::LatchMode::FOUR3);

// DISPLAY-EINSTELLUNGEN
#define SCREEN_WIDTH 128
#define SCREEN_HEIGHT 64
Adafruit_SH1106G display(SCREEN_WIDTH, SCREEN_HEIGHT, &Wire, -1);

// PUNKT-STRUKTUR
struct point2D {
  float x;
  float y;
};

// STATE MACHINE
enum UI_STATE {
    ST_MENU,
    ST_PLAY,

    ST_SETUP_WARNING,
    ST_SETUP_LENGTH,

    ST_NODE_START,
    ST_NODE_POS,
    ST_NODE_HEIGHT,
    ST_NODE_TYPE,

    ST_NODE_END
};

UI_STATE uiState = ST_MENU;

// UI-VARIABLEN
int lastPos = -1;
int menuSelection = 0;

// BUTTON ENTPRELLEN

bool isButtonPressed() {
    static bool stableState = HIGH;
    static bool lastReading = HIGH;
    static unsigned long lastChange = 0;
    const unsigned long debounceTime = 30;

    bool reading = digitalRead(PIN_SW);

    if (reading != lastReading) {
        lastChange = millis();
    }

    if ((millis() - lastChange) > debounceTime) {
        if (stableState == HIGH && reading == LOW) {
            stableState = reading;
            return true;   // nur einmal pro Druck
        }
        stableState = reading;
    }

    lastReading = reading;
    return false;
}

// GLOBALE VARIABLEN
Adafruit_NeoPixel strip(0, LED_PIN, NEO_GRB + NEO_KHZ800);  // NeoPixel-Objekt (Länge wird in setup() gesetzt)
uint16_t ledCount;          // aktuelle Länge des Streifens
uint16_t currentLED = 0;
int lengthSpeed = 0;
unsigned long lastLengthMove = 0;
unsigned long lastLengthDecel = 0;
const int lengthMaxSpeed = 10;

// NODES
struct Node {
  uint16_t pos;
  uint16_t height;
  uint8_t type;
};

Node* nodes = nullptr;
uint16_t nodeCount = 0;
Node currentNode = {}; //Erzeugt die Variable und setzt alle Werte der ersten Node auf 0


/////////////////////////////////////////////////////////
// V A R I A B L E N   F Ü R   B E R E C H N U N G E N //
/////////////////////////////////////////////////////////

// POINTS

// Array mit Pointer für 2D-Punkte, um die Punkte für die Bezierkurven zu berechnen
point2D* points = nullptr;
uint16_t pointCount = 0;
const int steps = 200;       // Feinheit der Längenberechnung
int targetLength = 0;   //Distanz von p1 zu p2 in LEDs
const float tolerance = 0.001; // Genauigkeit

int startHeight; //Höhe des Startpunkts
int endHeight;  //Höhe des Endpunkts

// Punkte für Bezierberechnung
point2D p1;
point2D c1;
point2D c2;
point2D p2;

// BEZIER

// Array mit Pointer für die Bezier-Kurvenpunkte
point2D* bezierPoints = nullptr;
uint16_t bezierPointCount = 0;
const int intSteps = 20; // Interpolationsschritte der finalen Bezierkurve

// SEGMENTS AND ACCELERATION
struct SegmentData{
  float distance;
  float acc;
};

SegmentData* segments = nullptr;
uint16_t segmentCount = 0;

// PLAY
float pos = 0;
float vel = 0;
uint16_t startLedPos = 0;
// Timing
unsigned long lastTime = 0;
int currentSegment = 0;

// Helligkeit (steuerbar per Encoder im Play-Modus)
uint8_t playBrightness = 80;  // Startwert (0-255)




/////////////////////////
// V O I D   S E T U P //
/////////////////////////

void setup() {
    Serial.begin(115200);

    pinMode(PIN_SW, INPUT_PULLUP);
    pinMode(PIN_CLK, INPUT_PULLUP);
    pinMode(PIN_DT, INPUT_PULLUP);

    // LittleFS initialisieren (true = formatiert beim ersten Mal)
    if (!LittleFS.begin(true)) {
        Serial.println(F("LittleFS Fehler!"));
    }

    ledCount = 1000;

    // LED-Streifen-Länge setzen und initialisieren
    strip.updateLength(ledCount);
    strip.begin();
    strip.clear();
    strip.show();

    if(!display.begin(0x3C)) {
        Serial.println(F("SH1106 Fehler"));
        for(;;);
    }

    // Gespeicherte Play-Daten laden (falls vorhanden)
    if (loadPlayData()) {
        Serial.println("Play-Daten aus Flash geladen.");
    } else {
        Serial.println("Keine gespeicherten Daten gefunden.");
    }

    display.clearDisplay();
    Serial.println("System bereit. Modus: MENU");
}


///////////////////////
// V O I D   L O O P //
///////////////////////

void loop() {

  //ENCODER AUSLESEN
  encoder.tick();
  int newPos = encoder.getPosition();

  ///////////////////////////////
  // S T A T E   M A C H I N E //
  ///////////////////////////////

  switch (uiState) {
    
    /////////////////////////////
    // 0 - H A U P T M E N U E //
    /////////////////////////////
    
    case ST_MENU:
      if (newPos != lastPos) {
        if (newPos < 0) { encoder.setPosition(0); newPos = 0; }
        if (newPos >= 2) {encoder.setPosition(1); newPos = 1; }

        menuSelection = newPos;
        drawMainMenu();
        lastPos = newPos;
      }

      if (isButtonPressed()) {
        if (menuSelection == 0) {
          if (segments != nullptr) {
            uiState = ST_PLAY;
          } else {
            display.clearDisplay();
            display.setTextSize(1);
            display.setTextColor(SH110X_WHITE);
            display.setCursor(0, 0);
            display.println("Keine Daten! Bitte zuerst Setup durchfuehren.");
            display.display();
            delay(2000);
            drawMainMenu();
          }
        }
        else if (menuSelection == 1) uiState = ST_SETUP_WARNING;

        menuSelection = 0;
        lastPos = -1;
        encoder.setPosition(0);
      }
            
      break;
      

    ///////////////////////////
    // 1 - A B S P I E L E N //
    ///////////////////////////

    case ST_PLAY:

      // Maker Faire Werbung
      drawRunning();
      // Encoder steuert Helligkeit im Play-Modus
      if (newPos != lastPos) {
        int delta = (newPos - lastPos) * 10;  // 10er-Schritte pro Tick
        playBrightness = constrain((int)playBrightness + delta, 5, 255);
        lastPos = newPos;
      }
      moveLED();
      break;



    ///////////////////
    // 2 - S E T U P //
    ///////////////////

    ///////////////////////////
    // 2 . 1 - W A R N U N G //
    ///////////////////////////

    case ST_SETUP_WARNING:
      if (newPos != lastPos) {
        if (newPos < 0) { encoder.setPosition(0); newPos = 0; }
        if (newPos >= 2) {encoder.setPosition(1); newPos = 1; }
                    
        menuSelection = newPos;
        drawSetupWarning();
        lastPos = newPos;
      }
                    
      if (isButtonPressed()) {
        if (menuSelection == 0) {
          uiState = ST_SETUP_LENGTH;

          // Löscht Inhalte des Node-Arrays und setzt Strip auf maximale Länge
          ledCount = 1000;
          strip.updateLength(ledCount);
          nodes = new Node[ledCount];     //Node-Array mit der maximalen Größe ledCount
          nodeCount = 0;                  //Zähler für die erstellten Nodes
          currentNode = {};
          currentLED = 0;
          Serial.print("Node Setup resetted.");
        } else if (menuSelection == 1) {
          uiState = ST_MENU;
          Serial.print("Returned to menu. Node Setup intact.");
          Serial.print(nodeCount);
        }
        
        menuSelection = 0;
        lastPos = -1;
        encoder.setPosition(0);
        newPos = 0;
        currentLED = newPos;
      }

      break;

    /////////////////////////
    // 2 . 2 - L A E N G E //
    /////////////////////////

    case (ST_SETUP_LENGTH):
      // Encoder steuert die Geschwindigkeit, nicht direkt die Position
      if (newPos != lastPos) {
        int delta = newPos - lastPos;
        lengthSpeed += delta;
        lengthSpeed = constrain(lengthSpeed, -lengthMaxSpeed, lengthMaxSpeed);
        lastLengthDecel = millis();

        // Bei Speed ±1: Encoder bewegt Cursor direkt (1 Tick = 1 LED)
        if (abs(lengthSpeed) == 1) {
          if (delta > 0) currentLED++;
          else if (delta < 0 && currentLED > 0) currentLED--;
          drawSetupLength();
        }

        lastPos = newPos;
      }

      // Auto-Abbremsen wenn nicht gedreht wird
      if (lengthSpeed != 0 && millis() - lastLengthDecel >= 400) {
        lastLengthDecel = millis();
        if (lengthSpeed > 0) lengthSpeed--;
        else lengthSpeed++;
      }

      // Ab Speed >=2: Cursor bewegt sich zeitgesteuert
      if (abs(lengthSpeed) >= 2) {
        unsigned long interval = 200 / abs(lengthSpeed);  // schneller bei höherem Speed
        if (interval < 20) interval = 20;                 // Minimum 20ms
        if (millis() - lastLengthMove >= interval) {
          lastLengthMove = millis();
          if (lengthSpeed > 0) {
            currentLED++;
          } else {
            if (currentLED > 0) currentLED--;
          }
          drawSetupLength();
        }
      }
 
      if (isButtonPressed()) {
 
        ledCount = currentLED + 1;  //Speichert die Länge des Streifens
        display.clearDisplay();
        display.display();
 
        for(int i = currentLED; i >= 0; i--) {
          currentLED = i;
          Serial.print(currentLED);
          strip.clear();
          strip.setPixelColor(0, strip.Color(0, 0, 100));            //Erste LED
          strip.setPixelColor(currentLED, strip.Color(0, 100, 0));  //Cursor-LED
          strip.setPixelColor(ledCount-1, strip.Color(0, 0, 100));
          strip.show();
          delay(10);
        }
 
        lengthSpeed = 0;
        lastPos = -1;
        encoder.setPosition(0);
        newPos = 0;
        currentLED = newPos;
        //uiState = ST_NODE_POS;
        uiState = ST_NODE_START;
 
      }
 
    break;
    

    /////////////////////////////////////////
    // 2 . 3 - S C H E I T E L P U N K T E //
    /////////////////////////////////////////

    ///////////////////////////
    // 2 . 3 . 0 - S T A R T //
    ///////////////////////////

    case (ST_NODE_START):
      if (newPos != lastPos) {
        if (newPos < 0) { encoder.setPosition(ledCount-1); newPos = ledCount-1; }
        if (newPos > ledCount-1) { encoder.setPosition(0); newPos = 0; }

      currentNode.pos = newPos;
      Serial.print("Position: ");
      Serial.println(currentNode.pos);
      currentLED = newPos;
      drawNodeStart();
      lastPos = newPos;

      }
      if (isButtonPressed()) {

        display.clearDisplay();
        display.display();

        encoder.setPosition(0);
        lastPos = -1;
        uiState = ST_NODE_HEIGHT;

      }
      break;



    /////////////////////////////////
    // 2 . 3 . 1 - P O S I T I O N //
    /////////////////////////////////

    case (ST_NODE_POS):
      if (newPos != lastPos) {
        if (newPos < 0) { encoder.setPosition(ledCount-1); newPos = ledCount-1; }
        if (newPos > ledCount-1) { encoder.setPosition(0); newPos = 0; }

      currentNode.pos = newPos;
      Serial.print("Position: ");
      Serial.println(currentNode.pos);
      currentLED = newPos;
      drawNodePos();
      lastPos = newPos;

      }
      if (isButtonPressed()) {

        display.clearDisplay();
        display.display();

        encoder.setPosition(0);
        lastPos = -1;
        uiState = ST_NODE_HEIGHT;

      }
      break;
                    
    ///////////////////////////
    // 2 . 3 . 2 - H O E H E //
    ///////////////////////////

    case (ST_NODE_HEIGHT):
      if (newPos != lastPos) {
        if (newPos < 0) { encoder.setPosition(0); newPos = 0; }

      currentNode.height = newPos;
      Serial.print("Height: ");
      Serial.println(currentNode.height);
      drawNodeHeight();
      lastPos = newPos;

      }

      if (isButtonPressed()) {

        display.clearDisplay();
        display.display();

        encoder.setPosition(currentNode.pos);
        lastPos = -1;
        currentLED = currentNode.pos;

        if (nodeCount == 0) {
          currentNode.type = 0; //Startpunkt
          nodes[nodeCount++] = currentNode;
          currentNode = {}; //Reset
          uiState = ST_NODE_POS;
        } else {
          uiState = ST_NODE_TYPE;
          menuSelection = 1;
          encoder.setPosition(menuSelection);
        }

      }
      break;

    ///////////////////////
    // 2 . 3 . 3 - T Y P //
    ///////////////////////
                    
    case (ST_NODE_TYPE):
      if (newPos != lastPos) {
        if (newPos < 1) {encoder.setPosition(1); newPos = 1; }
        if (newPos > 2) {encoder.setPosition(2); newPos = 2; }
                    
        menuSelection = newPos;
        currentNode.type = menuSelection;
        currentLED = currentNode.pos;

        Serial.print("Type: ");
        Serial.println(currentNode.type);

        drawNodeType();
        lastPos = newPos;
      }

      if (isButtonPressed()) {

        display.clearDisplay();
        display.display();

        encoder.setPosition(currentNode.pos);
        lastPos = -1;
        currentLED = currentNode.pos;

        if(currentNode.type == 2) {
          uiState = ST_NODE_END;
        } else {
          uiState = ST_NODE_POS;
        }

        if (nodeCount < ledCount) {
          nodes[nodeCount++] = currentNode;
          currentNode = {};
          Serial.print("Node gespeichert. Gesamt: "); Serial.println(nodeCount);
        } else {
          Serial.println("Max Nodes erreicht!");
        }

      }
      break;


    case (ST_NODE_END):

      display.clearDisplay();
      display.display();

      strip.clear();
      strip.show();

      for (int i = 0; i < nodeCount; i++) {
        Serial.print("Node ");
        Serial.print(i);
        Serial.print(" -> ");
        Serial.print("pos: ");
        Serial.print(nodes[i].pos);
        Serial.print(", height: ");
        Serial.print(nodes[i].height);
        Serial.print(", type: ");
        Serial.println(nodes[i].type);
      }

      encoder.setPosition(0);
      lastPos = -1;

      startLedPos = nodes[0].pos;
      strip.updateLength(ledCount);


      // LETZTE BERECHNUNGEN
      calculations();
      printPoints();

      bezierCalculations();
      printBezierPoints();

      segmentCalculations();
      printSegments();

      // Play-Daten im Flash speichern und neu starten
      savePlayData();
      Serial.println("Neustart...");
      delay(500);
      ESP.restart();

  } //SWITCH END

} //LOOP END


/////////////////////////////////
// M E N U E - G R A F I K E N //
/////////////////////////////////

void drawMainMenu() {
    display.clearDisplay();
    display.setTextSize(1);
    display.setTextColor(SH110X_WHITE);

    display.setCursor(0, 10);
    display.println(menuSelection == 0 ? "> ABSPIELEN" : "  ABSPIELEN");

    display.setCursor(0, 30);
    display.println(menuSelection == 1 ? "> KONFIGURIEREN" : "  KONFIGURIEREN");

    display.display();
}

void drawSetupWarning() {
  display.clearDisplay();
  display.setTextSize(1);
  display.setTextColor(SH110X_WHITE);

  display.setCursor(0, 0);
  display.println("Alle Einstellungen werden entfernt. Weiter?");

  display.setCursor(0, 40);
  display.println(menuSelection == 0 ? "> JA" : "  JA");

  display.setCursor(32, 40);
  display.println(menuSelection == 1 ? "> NEIN" : "  NEIN");

  display.display();
}

void drawSetupLength() {

  display.clearDisplay();
  display.setTextSize(1);
  display.setTextColor(SH110X_WHITE);

  display.setCursor(0, 0);
  display.println("LED-Cursor mit dem");
  display.println("Drehencoder zu der");
  display.println("letzten LED bewegen");
  display.println("und druecken.");

  //Zeigt die Länge des Streifens auf dem Display an.
  //display.setTextSize(3);
  //display.setCursor(64, 32);
  //display.println(currentLED+1);

  display.display();

  //Zeige Einstellungen mit LEDs an
  drawSetupLeds();

}

void drawNodeStart() {

  display.clearDisplay();
  display.setTextSize(1);
  display.setTextColor(SH110X_WHITE);

  display.setCursor(0, 0);
  display.println("LED zum hoechsten");
  display.println("Punkt der Strecke");
  display.println("bewegen und den");
  display.println("Encoder druecken.");

  //Gibt die aktuelle LED auf dem Display aus.
  //display.setTextSize(3);
  //display.setCursor(64, 32);
  //display.println(currentLED+1);

  display.display();

  //Zeige Einstellungen mit LEDs an
  drawSetupLeds();

}

void drawNodePos() {

  display.clearDisplay();
  display.setTextSize(1);
  display.setTextColor(SH110X_WHITE);

  display.setCursor(0, 0);
  display.println("LED zum folgenden");
  display.println("Scheitelpunkt bewegen");
  display.println("und Encoder druecken.");

  //Gibt die aktuelle LED auf dem Display aus.
  //display.setTextSize(3);
  //display.setCursor(64, 32);
  //display.println(currentLED+1);

  display.display();

  //Zeige Einstellungen mit LEDs an
  drawSetupLeds();

}

void drawNodeHeight() {

  display.clearDisplay();
  display.setTextSize(1);
  display.setTextColor(SH110X_WHITE);

  display.setCursor(0, 0);
  display.println("Hoehe einstellen und den Encoder druecken:");

  display.setTextSize(3);
  display.setCursor(64, 32);
  display.println(currentNode.height);

  display.display();

  //Zeige Einstellungen mit LEDs an
  drawSetupLeds();

}

void drawNodeType() {

  display.clearDisplay();
  display.setTextSize(1);
  display.setTextColor(SH110X_WHITE);

  display.setCursor(0, 0);
  display.println("Art des Punktes");
  display.println("bestimmen:");

  display.setCursor(0, 20);
  display.println(menuSelection == 1 ? "> Scheitelpunkt" : "  Scheitelpunkt");

  display.setCursor(0, 30);
  display.println(menuSelection == 2 ? "> Endpunkt" : "  Endpunkt");

  display.display();

  //Zeige Einstellungen mit LEDs an
  drawSetupLeds();

}

void drawRunning() {

  display.clearDisplay();
  display.setTextSize(1);
  display.setTextColor(SH110X_WHITE);

  display.setCursor(0, 0);
  display.println("Wer hat noch nicht,");
  display.println("wer will noch mal?");
  display.println("Anschnallen bitte!");
  display.println("Die naechste Runde");
  display.println("geht los-os-os-s.");

  display.display();

}


void drawSetupLeds() {

  strip.clear();

  //Start und Ende
  strip.setPixelColor(0, strip.Color(0, 0, 100));
  strip.setPixelColor(ledCount-1, strip.Color(0, 0, 100));

  //Bereits gespeicherte Nodes farblich nach Typ
  for (uint16_t i = 0; i < nodeCount; i++){
    uint8_t r = 0, g = 0, b = 0;

    switch(nodes[i].type) {
      case 0: //Startpunkt
        r = 80; g = 80; b = 80; //weiß
        break;
      case 1: //Scheitelpunkt
        r = 100; g = 0; b = 100; //pink
        break;
      case 2: //Tunnel
        r= 100; g = 65; b = 0; //orange
        break;
      case 3: //Endpunkt
        r = 100; g = 0; b = 0;
        break;
    }
    strip.setPixelColor(nodes[i].pos, strip.Color(r, g, b));
  }

  //Bewegliche LED
  strip.setPixelColor(currentLED, strip.Color(0, 100, 0));
  strip.show();

}


///////////////////////////////////////////
///////////////////////////////////////////
///// F U N K T I O N E N   F U E R   /////
///// D I E   B E R E C H N U N G E N /////
///////////////////////////////////////////
///////////////////////////////////////////

// Die lerp-Funktion, was Bezier 1. Grades ist
point2D lerp(point2D a, point2D b, float t) {
  return {
    a.x + t * (b.x - a.x),
    a.y + t * (b.y - a.y)
  };
}

// Die Bezierfunktion 3. Grades
point2D bezier(point2D p1, point2D c1, point2D c2, point2D p2, float t) {
  point2D a = lerp(p1, c1, t);
  point2D b = lerp(c1, c2, t);
  point2D c = lerp(c2, p2, t);
  point2D d = lerp(a, b, t);
  point2D e = lerp(b, c, t);
  return lerp(d, e, t);
}


// Umrechnung der Nodes auf dem LED-Streifen in 2D-Punkte
void calculations() {

  points = new point2D[ledCount];     //Node-Array mit der maximalen Größe ledCount

  points[0] = {0, nodes[0].height};
  pointCount = 1;                  //Zähler für die erstellte erste Node

  for(int i = 0; i < nodeCount - 1; i++) {

    int posCurrent = nodes[i].pos;
    int posNext = nodes[i+1].pos;

    if (posNext >= posCurrent) {
      targetLength = posNext - posCurrent;
    } else {
      targetLength = (ledCount - posCurrent) + posNext;
    }

    startHeight = nodes[i].height;
    endHeight = nodes[i+1].height;

    Serial.print("Segment ");
    Serial.print(i);
    Serial.print(": pos ");
    Serial.print(posCurrent);
    Serial.print(" -> ");
    Serial.print(posNext);
    Serial.print(" = ");
    Serial.print(targetLength);
    Serial.println(" LEDs");

    float a = findA();
    points[i+1] = {points[i].x+a, nodes[i+1].height};
    pointCount++;

    Serial.print("Gefundenes a = ");
    Serial.println(a, 6);
  }

  // Schließt den Kreis
  int posLast = nodes[nodeCount-1].pos;
  int posFirst = nodes[0].pos;

  if (posFirst >= posLast) {
    targetLength = posFirst - posLast;
  } else {
    targetLength = (ledCount - posLast) + posFirst;
  }

  startHeight  = nodes[nodeCount - 1].height;
  endHeight    = nodes[0].height;

  Serial.print("Closing segment: pos ");
  Serial.print(posLast);
  Serial.print(" -> ");
  Serial.print(posFirst);
  Serial.print(" = ");
  Serial.print(targetLength);
  Serial.println(" LEDs");

  float a = findA();

  points[pointCount] = {points[pointCount - 1].x+a, nodes[0].height};

  pointCount++; //da nodes[0] mit reinzählt, ist pointCount 1 größer als nodeCount

  Serial.print("Gefundenes a (closing) = ");
  Serial.println(a, 6);

  Serial.print("pointCount: ");
  Serial.println(pointCount);

}

// Funktion, um die Kurvenlänge zu berechnen
float bezierLength(float aValue){
  p1 = {0, startHeight};
  c1 = {aValue / 2.0f, startHeight};
  c2 = {aValue / 2.0f, endHeight};
  p2 = {aValue,        endHeight};

  float length = 0;
  point2D prev = bezier(p1, c1, c2, p2, 0);

  for (int i = 0; i < steps; i++){
    float t = (float)i / (steps - 1);
    point2D curr = bezier(p1, c1, c2, p2, t);

    // Abstand addieren
    float dx = curr.x - prev.x;
    float dy = curr.y - prev.y;
    length += sqrt(dx*dx + dy*dy);

    prev = curr;
  }

  return length;
}
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

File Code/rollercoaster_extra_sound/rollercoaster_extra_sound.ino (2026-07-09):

#include <Arduino.h>
#include <Wire.h>
#include <Adafruit_GFX.h>
#include <Adafruit_SH110X.h>
#include <RotaryEncoder.h>
#include <Adafruit_NeoPixel.h>
#include <LittleFS.h>
#include <DFRobotDFPlayerMini.h>   // NEU: DFPlayer Mini Bibliothek

// ==========================================
// PIN- & HARDWARE-EINSTELLUNGEN
// ==========================================
#define LED_PIN 33

#define PIN_CLK 25
#define PIN_DT  26
#define PIN_SW  27
RotaryEncoder encoder(PIN_CLK, PIN_DT, RotaryEncoder::LatchMode::FOUR3);

// NEU: DFPlayer Mini an Hardware-Serial2
#define DFP_RX_PIN 16   // ESP32 RX2  <-- an TX vom DFPlayer
#define DFP_TX_PIN 17   // ESP32 TX2  --> an RX vom DFPlayer (über 1kOhm Widerstand!)

HardwareSerial dfpSerial(2);       // UART2 des ESP32
DFRobotDFPlayerMini dfPlayer;
bool dfpReady = false;             // Merker: Player erfolgreich initialisiert?

// NEU: Sound-Einstellungen
uint8_t soundVolume = 10;          // Lautstärke 0-30
uint8_t soundEnabled = 1;          // 0 = Aus, 1 = An
uint8_t soundMode = 0;             // 0 = Effekte (Status-Sounds), 1 = Random (Zufallswiedergabe)
uint8_t effectLoopTrack = 0;   // NEU: Track, der im Modus "Nur Effekte" geloopt wird (0 = keiner)

#define SCREEN_WIDTH 128
#define SCREEN_HEIGHT 64
Adafruit_SH1106G display(SCREEN_WIDTH, SCREEN_HEIGHT, &Wire, -1);

// ==========================================
// GRUNDLEGENDE STRUKTUREN
// ==========================================
struct point2D {
  float x;
  float y;
};

// Element-Arten
const char* elementArtNames[] = {
  "Hill", "Loop", "Helix", "Steilkurve", "Valley", "Lift", "Brake", "Booster"
};
const int NUM_ARTEN = 8;

struct Node {
  uint16_t pos;
  uint16_t height;
  uint8_t  type;    // 0=Startpunkt, 1=Scheitelpunkt, 2=Endpunkt
  uint8_t  art;     // 0=Kuppe, 1=Loop, 2=Helix, 3=Steilkurve, 4=Bottom, 5=Lift, 6=Bremse, 7=Booster
  float    force;   // Einstellbarer Wert (Lift: m/s, Bremse: Ziel m/s, Booster: Schub)
  uint16_t length;  // Länge der Funktionszone in Fließrichtung (LEDs)
  uint8_t  enabled; // 0 = deaktiviert, 1 = aktiv (nur relevant für art >= 5)
};

Node* nodes = nullptr;
uint16_t nodeCount = 0;
Node currentNode = {};

struct SegmentData {
  float distance;
  float acc;
  float angle;      // Winkel des Segments
  float curvature;  // Krümmung für G-Kraft (Zentripetalbeschleunigung)
};

SegmentData* segments = nullptr;
uint16_t segmentCount = 0;

// ==========================================
// NEU: SOUND-DEFINITIONEN
// ==========================================
// Dateien auf der SD-Karte im Ordner /mp3:
// 0001.mp3 = Kettenlift (Klackern, Loop-fähig)
// 0002.mp3 = Booster / Launch
// 0003.mp3 = Bremsen (Zischen)
// 0004.mp3 = Freie Fahrt / Fahrtwind (Loop-fähig)
// 0005.mp3 = Start-Jingle (beim Betreten von ABSPIELEN)
#define SND_LIFT      1
#define SND_BOOSTER   2
#define SND_BRAKE     3
#define SND_RIDE      4
#define SND_THEME     4   
#define SND_START     5
#define ADV_LIFT      1    // NEU: Einwuerfe in /ADVERT
#define ADV_BOOSTER   2
#define ADV_BRAKE     3
#define ADV_START     4    // Welcome-Jingle als Einwurf
#define RANDOM_FOLDER 2 // Ordner "02" auf der SD-Karte

bool themeRunning = false;  // NEU: Laeuft der Theme-Loop?

String lastSoundStatus = "";   // Zuletzt vertonter Status
static unsigned long lastSoundCmd = 0;
int randomFolderCount = 0;       // Anzahl Dateien im Random-Ordner (wird im Setup ermittelt)
bool randomModeActive = false;   // Läuft gerade die Random-Wiedergabe?

//void playSound(uint8_t track, bool loopIt = false) {
//    if (!dfpReady || !soundEnabled) return;
//    if (loopIt) dfPlayer.loopFolder(0);  // Vorsichtshalber Loop beenden... 
//    if (loopIt) dfPlayer.loop(track);    // ...und Track als Endlosschleife starten
//    else        dfPlayer.playMp3Folder(track);
//}

void playRandomSound() {
    if (!dfpReady || !soundEnabled || randomFolderCount <= 0) return;
    int track = random(1, randomFolderCount + 1);   // 1 bis N (obere Grenze exklusiv)
    dfPlayer.playFolder(RANDOM_FOLDER, track);
    lastSoundCmd = millis();
}

void stopSound() {
    if (!dfpReady) return;
    randomModeActive = false;
    themeRunning = false;
    effectLoopTrack = 0;   // NEU
    dfPlayer.disableLoop();   // NEU
    dfPlayer.stop();
    lastSoundStatus = "";
}

// Wird bei jedem Physik-Durchlauf aufgerufen, reagiert nur auf Statuswechsel
void updateSound(String status) {
    if (!dfpReady || !soundEnabled) return;

    if (soundMode == 1) {   // RANDOM
        if (!randomModeActive && randomFolderCount > 0) {
            randomModeActive = true;
            playRandomSound();
        }
        return;
    }

    if (soundMode == 2) return;   // NEU: NUR THEME - Status ist egal, Theme laeuft einfach

    // Kategorie bilden (fuer Modus 0 und 3)
    String cat;
    if (status == "KETTENLIFT")   cat = "LIFT";
    else if (status == "BOOSTER") cat = "BOOST";
    else if (status == "BREMSEN") cat = "BRAKE";
    else                          cat = "RIDE";

    if (cat == lastSoundStatus) return;
    if (millis() - lastSoundCmd < 150) return;
    lastSoundCmd = millis();
    String prevCat = lastSoundStatus;
    lastSoundStatus = cat;

    if (soundMode == 0) {   // THEME+FX: Einwuerfe per Advertise
        if (cat == "LIFT")       dfPlayer.advertise(ADV_LIFT);
        else if (cat == "BOOST") dfPlayer.advertise(ADV_BOOSTER);
        else if (cat == "BRAKE") dfPlayer.advertise(ADV_BRAKE);
        else if (prevCat == "LIFT") dfPlayer.stopAdvertise();
    }
    else {                  // NEU - NUR EFFEKTE: normale Tracks, Stille dazwischen
        if (cat == "LIFT")       { effectLoopTrack = SND_LIFT; dfPlayer.playMp3Folder(SND_LIFT); }
        else if (cat == "BOOST") { effectLoopTrack = 0; dfPlayer.playMp3Folder(SND_BOOSTER); }
        else if (cat == "BRAKE") { effectLoopTrack = 0; dfPlayer.playMp3Folder(SND_BRAKE); }
        else                     { effectLoopTrack = 0; dfPlayer.stop(); }   // RIDE = Stille
    }
}
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

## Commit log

2026-05-14 Features added (Telemetrie, Trackeditor, Trackslots, ColorManagement, Lift/Brake/Booster etc)
2026-05-15 feat: umfangreiches UI- & Telemetrie-Update inkl. Zonen-Logik und V2 Dateisystem
    - feat(ui): Dynamisch scrollbares Edit-Menü für Elemente integriert
    - feat(telemetry): Max-Speed-Tracking ("maxReachedSpeed") im Kirmes- und Telemetrie-Modus hinzugefügt
    - fix(telemetry): Ziel-Logik überarbeitet; unterscheidet nun korrekt zwischen aktuell aktiver Zone (AKTIV) und vorausliegendem Ziel (ZIEL) inkl. Rundkurs-Korrektur
    - feat(core): Neues "enabled"-Flag für Funktions-Nodes hinzugefügt, um Zonen temporär zu deaktivieren (dimmt die LEDs der Zone)
    - refactor(storage): Dateisystem auf Version 2 aktualisiert (Magic-Byte Implementierung) inkl. automatischer V1-Migration beim Laden alter Slots
    - cho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
2026-07-04 sound stage, codecopy
2026-07-04 some tests, waiting for original dfplayer (china replicas unfortunatly have some bugs)
    [rollercoaster_extra_sound.ino]
